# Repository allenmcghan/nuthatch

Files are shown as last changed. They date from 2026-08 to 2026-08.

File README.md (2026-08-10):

# Nuthatch — An Open Single-Seat Ultralight

The Part 103 fleet is mostly 1980s designs. They are cheap, they are buildable in
a garage, and they hurt people in a small number of well-understood ways:

- **Ground loops**, because almost all of them are taildraggers
- **Stall-spin departures**
- **Nothing structural ahead of the pilot's legs**
- **Lap belts instead of harnesses**
- **A 7:1 glide**, so an engine failure leaves you very few fields to choose from

Every one of those is fixable for roughly 100 build hours and $1,900. Nuthatch is
what that looks like.

A single-seat wood-and-steel ultralight derived from the TEAM Sky Pup and Ison
Airbike. Plans, drawings, calculations, build log, and measured flight data all
live here. So do the mistakes.

**Named after the only bird that climbs down a tree headfirst.** Small, plain, and
does it backwards from everything else in the class.

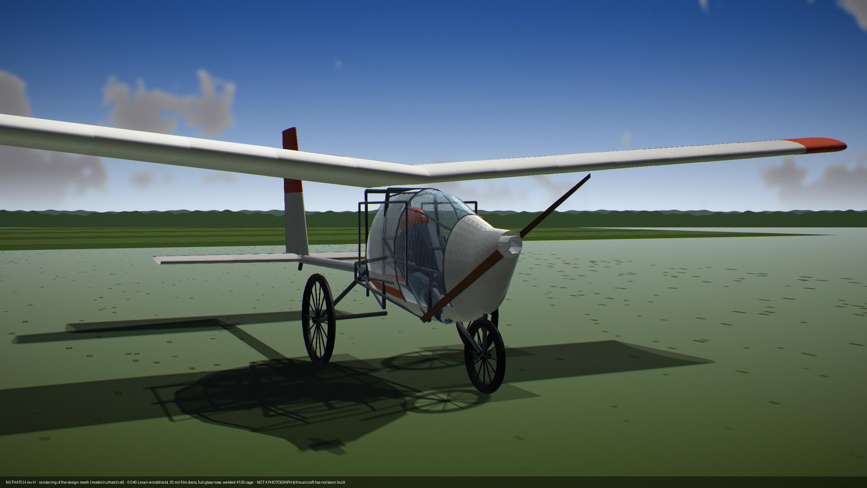
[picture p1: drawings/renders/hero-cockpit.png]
Nuthatch rev H


*A rendering of the design mesh, not a photograph — this aircraft has not been
built. Generated from `model/nuthatch.stl` by `analysis/render-hero.py`.*

**Status: entering final design.** The configuration is settled and reasoned;
the structure is not drawn. There is a 3D model, a drawing set, CAD exports of
the steel frame and a measured visibility analysis — and **no member has been
sized against a load case.** [docs/open-questions.md](docs/open-questions.md)
opens with the four items that gate everything else.

---

## Design targets

| | |
|---|---|
| Cost, materials | under $15,000 |
| Build hours | under 750 |
| Takeoff roll | under 200 ft |
| Fits | a 22 ft garage and a 16 ft flatbed trailer |
| Part 103 | a compliant configuration off the same drawings |

## Current specification

Two configurations, one set of drawings. See [docs/specs.md](docs/specs.md).

| | EAB build | Part 103 build |
|---|---|---|
| Empty weight | 296 lb\* | 250 lb\* |
| Gross | 580 lb | 450 lb |
| Span / area | 31 ft / 130 ft² | same |
| Stall, flaps 40° | 28.4 mph | 22.9 kt |
| Takeoff roll | 140 ft | ~160 ft |
| Climb | 1,010 fpm | ~500 fpm |
| Glide ratio | 12.4† | 12.4† |
| Cruise | 55–60 mph | 55 kt limited |
| Range | ~150 mi | fuel limited |
| Engine | Hirth F-33, 28 hp | direct-drive, ~16 hp |
| Brakes | yes | yes |

\* **Empty weight: two statements, deliberately not reconciled.** The workbook
omits rows (slats — since retired for flaps — and cabane) that the build-log
CSV carries; honest totals are ~308 / ~262 lb. The scrubbed single-build path
reaches 253.2, and the rev G cabane deletion takes the 103 kit to **247.7**.
Reconciliation is parked until the frame is redrawn — see
[docs/specs.md](docs/specs.md).

† **Glide 12.4, not the 10.7 this repo quoted for a long time.** Rev G lowered
the wing onto the cabin roof and deleted the cabane: f 4.84 → 3.68 ft², L/D
10.8 → 12.4. The §22 drag cleanup would take it to 13.6, but that is proposed,
not adopted. Nothing here is measured.

**Powerplant roadmap: gasoline first, hybrid second, electric third.** Electric,
when it comes, is an EAB-only path — a Part 103 all-electric build has 8 lb of
battery budget left after the airframe and drive, which is about four minutes.
Part 103 stays gasoline. Worked in
[docs/trades/pusher-vs-tractor.md](docs/trades/pusher-vs-tractor.md).

## Configuration

- Nose-mounted tractor propeller. Pusher was analysed and rejected for the
  gasoline aircraft: efficiency is a wash, and it does not close on balance
- Welded 4130 cockpit cage + single straight 4130 tail boom, all-wood
  cantilever wing sitting directly on the cabin roof (no cabane), fabric
  over everything
- Reclined pilot; **the entire nose is glazed** — from the cowl joint back to
  the wing leading edge and down to the cage's lower longeron, in thin (0.040)
  Lexan. The engine cowl is the only opaque panel forward of the pilot. The two
  doors are thin clear film; a mounted film cutter is the egress tool
- Ram-air NACA ducts, closable for winter — the cabin deletes ~20 °F of wind
  chill rather than making heat. **Doors both sides are an EAB kit item**;
  the Part 103 aircraft carries the windshield and vents without them
- Constant chord, 3-piece removable wing, two bolts per cap per joint
- Douglas fir truss ribs, plywood D-tube leading edge, Oratex covered
- Aluminum tube spar caps with a wrapped sheet shear web
- Single-lever plain flaps, inboard ~60% span (0/25/40°, one-piece torque
  tube; replaced the fixed slats — [docs/trades/flaps.md](docs/trades/flaps.md))
- Two-axis control: elevator and rudder, roll via spoilerons and dihedral —
  one stick (pitch fore/aft, spoilerons lateral, twist-grip rudder), left-hand
  symmetric spoiler lever for glidepath; no rudder pedals
- Tricycle gear, castoring raked nose leg, trailing-arm mains with MTB
  coil-overs, bicycle hydraulic disc brakes
- Structural nose bow ahead of the pilot's feet, rollover hoop, 5-point
  harness anchored to the cage, mesh sling seat over a crushable
  bottom-out pad (energy-absorbing, without the rebound of a bare sling)
- BRS hard points designed in

## What makes it different

**Glide.** 12.4:1 predicted against roughly 7 or 8 for the aluminum-and-Dacron
aircraft in this class. That is a safety number as much as an efficiency one: engine-out you
reach twice the ground area.

**Crash structure.** Steel tube nose bow forward of the pedals and a rollover
hoop behind your head, so there is a survivable volume rather than fabric.

**Visibility, measured.** 61.3% of the whole sphere gets out, and 42% of the
±30° ahead-and-down sector a pilot lands on — against 40.0% and 4% for the
half-glazed version this replaced. Ray-cast from the pilot's eye against the
same mesh the drawings come from, in
[analysis/visibility.py](analysis/visibility.py). The straight-ahead view is
limited by the **engine**, not the glazing, and that is written down too.

**No ground loop.** Tricycle gear with a steerable nose.

**No aileron spin mode.** Roll comes from spoilerons, which produce proverse yaw
and cannot be cross-controlled into a spin.

**A fail-safe autopilot path.** Spoilerons are single-acting with spring return,
so an autopilot servo has no failure mode that takes roll control away from the
pilot. See [Junco](https://github.com/allenmcghan/junco).

## Repository layout

```
docs/specs.md        the current specification, one page, with sources
docs/design-log.md   every decision and the number behind it
docs/open-questions.md   what blocks drawing, most-blocking first
docs/trades/         21 worked configuration trades — index in its README
analysis/            the models: frame, aero, visibility, weights, CAD export,
                     geometry and renderers. Everything regenerates from here
cad/                 DXF, AutoCAD script, tube schedule — from analysis/frame.py
drawings/sheets/     GA-001, LG-001, CP-001, ST-001 + the collected PDF
drawings/renders/    shaded renderings and the visibility chart
model/               nuthatch.stl (rev H) and the quarter-scale validation plan
build-log/           measured weights against estimates, failures
flight-test/         Phase I plan and logged data
```

Detail drawings (`drawings/wing`, `fuselage`, `tail`, `gear`, `fittings`) are
empty placeholders — that is the work of the final design phase.

## CAD

The steel frame lives in [analysis/frame.py](analysis/frame.py) as a node and
member table — not as drawing geometry. Everything downstream reads it, so
moving a node updates the STL, the drawings, the cut list, the weight and the
visibility numbers together. [cad/](cad/) holds the generated DXF, an AutoCAD
script and the tube schedule; `cad-export.py --from-dxf` reads an edited DXF
back. Recommended CAD and the round trip are in [cad/README.md](cad/README.md).

The first thing that check found: **the frame is currently in six disconnected
pieces** — see [docs/open-questions.md](docs/open-questions.md).

## The two files worth reading first

**[docs/design-log.md](docs/design-log.md)** — every decision and the number
behind it, including the configurations that lost and why. Drawings exist for a
dozen aircraft in this class. Reasoning does not.

**[build-log/measured-weights.csv](build-log/measured-weights.csv)** — estimated
against actual weight, part by part, as parts arrive. Every published weight in
this class is a claim. This one will be a measurement.

## Contributing

Corrections to the analysis are the most valuable contribution, especially on
spar sizing, flap geometry, and load cases. Open an issue with your numbers.

## License

Documentation and drawings: CERN-OHL-S v2 (see [LICENSE](LICENSE)).
Firmware and tooling, where present: MIT.

## Disclaimer

**This is an experimental amateur-built aircraft design published as a work in
progress. It has never been built or flown.**

Nothing here has been reviewed, certified, or validated by any authority. The
structural analysis is preliminary and every weight is an estimate until the
build log says otherwise. Slat geometry, spar sizing, and load cases are
explicitly unresolved.

If you build from this, **you are the manufacturer.** You are responsible for
your own structural analysis, your own airworthiness determination, and your own
decision to fly. No warranty of any kind is offered or implied, expressed or
otherwise, including fitness for any purpose.

Aircraft built to Part 103 require no pilot certificate. That does not make them
safe to fly without training. Get instruction.

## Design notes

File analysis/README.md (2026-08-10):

# analysis

The models. Every number quoted anywhere in this repo comes from one of these,
and every drawing, render and CAD file regenerates from them.

Most take an optional scratch-directory argument (where the intermediate mesh
JSON is written); with no argument they use the current directory.

## The source of truth

| | |
|---|---|
| **`frame.py`** | **the steel frame as a node table, a member table and a stock table.** Not a drawing — a design. Run it directly for the tube schedule, the joint angles and the connectivity check. Everything structural reads it |
| `geometry-mesh.py` | builds the whole aircraft: wing, tail, pod, glazing, cowl, boom, gear, plus the frame from `frame.py`. Writes `model/nuthatch.stl`, the mesh JSON and the general-arrangement sheet |

## Analysis

| | |
|---|---|
| `aero-model.py` | AeroSandbox + NeuralFoil: CLmax, Oswald efficiency, dihedral derivatives |
| `visibility.py` | ray-cast from the pilot's eye — what the pilot can see, and what blocks it |
| `trim-tail.py` | tail sizing, trim, stick force, flare authority, rudder-roll rate |
| `weight-scrub.py` | line-by-line weight scrub against the Part 103 cap |
| `common-airframe.py` | the two-configuration fleet: balance, Vne, ballast |
| `gear-design.py` | stance, stroke, drop loads, nose-over protection |
| `flaps.py` | flap increment, VFE, stall margin |
| `cage-design.py` | all-steel boom trade, wing attach loads, cage station convergence |
| `enclosed-cockpit.py` | recline, CG, wing height, drag, the rev G ledger |
| `glazing-ventilation.py` | glazing weight (measured off the mesh), tautness, ram-air flow, wind chill, egress, the enclosure ledger |
| `twist-grip-rudder.py` | wrist torque, horn balance, gearing |
| `sling-seat.py` | sling tension, crush pad, proof load |
| `borrowed-optimizations.py` | VGs, gap seals, drag cleanup, ground-adjustable prop |
| `fly-by-wire.py` | servo weights, hardover authority, the case against |
| `fuselage-boom.py` | **superseded in part** — boom sizing method stands, its aluminium answer does not |

## Output

| | |
|---|---|
| `cad-export.py` | writes `cad/` — DXF, AutoCAD script, tube schedule. `--from-dxf FILE` reads an edited DXF back |
| `cad-sheets.py` | the dimensioned drawing sheets, GA-001 / LG-001 / CP-001 / ST-001 |
| `render-hero.py` | shaded renderings, including the pilot's-eye view |
| `render-kxnx.py` | the takeoff renderings |

## Regeneration order

`frame.py` → `geometry-mesh.py` → everything else. If you change the frame or
the pod, run it in that order; the mesh JSON is what the CAD sheets, the
renderers and the visibility analysis all read.

```
python3 analysis/frame.py
python3 analysis/geometry-mesh.py
python3 analysis/cad-export.py
python3 analysis/cad-sheets.py
python3 analysis/visibility.py
python3 analysis/render-hero.py
```

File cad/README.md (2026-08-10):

# CAD

The steel frame, exported for a CAD package. **Everything in this folder is
generated** — `analysis/frame.py` is the source of truth, and
`analysis/cad-export.py` writes these files from it.

Units are **inches**. Datum is the aircraft datum used everywhere else in the
repo: **X aft from the propeller plane** (so X is the station number), **Y
right**, **Z up**, **ground at z = 0** with the gear at static. Set your CAD
units to inches and it lands in the right place with no scaling.

| File | What it is |
|---|---|
| `nuthatch-frame-3d.dxf` | 3D wireframe, every tube centreline, on layers by structure group, with node markers, node labels and datum/station reference lines. **This is the one to open and start moving.** |
| `nuthatch-views-2d.dxf` | Side / top / front orthographic projections on one flat sheet, with a station grid and waterlines. For drafting, not for editing. |
| `nuthatch-frame.scr` | An AutoCAD script that draws the same wireframe with `LINE` commands. For when a DXF import argues with you. |
| `tube-schedule.csv` | Cut list: every member, stock, centreline length, weight, and the tightest joint angle at each end. |
| `nodes.csv` | Every node, mirrored, with the members that land on it. |

`model/nuthatch.stl` alongside is the full aircraft as a mesh — good for
visualising and for checking clearances, useless for editing.

## Two things these files are not

**They are not a fabrication drawing.** No member has been sized against a
load case. `docs/open-questions.md` carries *"cage member sizing + a rollover
load basis"* as unresolved and no rollover standard has been chosen. The tube
sizes here carry the right geometry and a plausible weight and nothing more.
**Do not cut steel from them.**

**Lengths are centreline to centreline.** Deduct for the fishmouth at each
end. The `min_joint_angle` columns are there because that is what sets the
notch — anything much under 20° is a bad joint however well you cope it.

## The frame is currently in six disconnected pieces

Run `python3 analysis/frame.py`. Drawn as overlapping cylinders the cage looks
solid; drawn as a graph it is not. Only the 14-node cage box is welded
together. The rear frame, the tail boom and all three gear legs are islands,
and several nodes sit two to three inches away from the member they are
supposed to land on — close enough to read as a joint on a drawing, not close
enough to be one in steel.

That is not a bug in the exporter. It is the actual state of the design, and
it is the first thing worth fixing. See `docs/open-questions.md`.

## Which CAD

**If you want to move geometry and get a cut list back: Onshape, free plan.**
Parametric, runs in a browser, and its **Frames** tool does exactly this job —
sweep tube profiles down a wireframe and it generates a cut list with miter
angles. The free tier requires documents to be public, which for a CERN-OHL-S
project is where the CAD should be anyway. Import `nuthatch-frame-3d.dxf` as a
sketch/curve set, then apply frame profiles to it.

**If you want it offline and open source: FreeCAD.** Matches the licence
posture of the repo. Weaker weldment story than Onshape but it will do it.

**AutoCAD works for what you asked for.** The 3D DXF is native LINE geometry
on sensible layers; move endpoints, add members, delete members. What AutoCAD
will not give you is a cut list or a weight — which is what the round trip
below is for.

**If you have access to SolidWorks, its Weldments module is still the best
tool for this specific job** — structural members along a 3D sketch, automatic
cut list with lengths and end angles. It is the only one of these that was
designed for tube frames from the start.

## Round trip

Edit the wireframe in CAD, save as DXF, then:

```
python3 analysis/cad-export.py --from-dxf path/to/edited.dxf
```

It parses the `LINE` entities, matches each endpoint to the nearest known
node, and reports what moved, what is new and what vanished — then prints a
node table in `frame.py` format to paste back in.

It reads **positions only.** Added members, deleted members and changed tube
sizes have to go into `_M` by hand: a DXF line has no way to tell you which
stock it is meant to be.

Once `frame.py` is updated, re-run and everything downstream follows:

```
python3 analysis/frame.py                    # weight, joints, connectivity
python3 analysis/cad-export.py               # these files
python3 analysis/geometry-mesh.py            # STL + mesh + general arrangement
python3 analysis/cad-sheets.py               # drawing sheets
python3 analysis/visibility.py               # what the pilot can see
python3 analysis/render-hero.py              # renders
```

Keep `frame.py` as the source of truth. If the CAD becomes the master, the
weights, the drawings and the visibility numbers quietly stop matching the
aeroplane.

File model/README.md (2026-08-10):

# model/

`nuthatch.stl` is the **full-size rev H aircraft**, generated by
`analysis/geometry-mesh.py` — cage, glazing, cowl and boom all modelled
explicitly. Good for visualising and checking clearances; not editable. The
editable frame is `analysis/frame.py`, exported to `cad/`.

The rest of this file is the quarter-scale validation aeroplane.

---

# Quarter-Scale Validation Model

Built before the full-size airframe to prove the handling before committing to a
garage build.

## Why quarter scale and not eighth

Reynolds number is the whole issue and scale is the only lever on it. For Froude
similarity, weight goes as scale cubed and speed as the square root:

| Scale | Span | Froude weight | Froude speed | Re |
|---|---|---|---|---|
| 1/8 | 46 in | 0.97 lb | 12 mph | 57,000 |
| 1/4 | 7.75 ft | 7.75 lb | 16.5 mph | 161,000 |
| Full | 31 ft | 496 lb | 33 mph | 1,280,000 |

Quarter scale is three times the Reynolds number and still an ordinary large RC
aircraft at 15 oz/ft². It is also big enough that the wing joint and the spoileron
linkage are real mechanisms rather than miniatures.

**Practical note:** at Re 161,000 the section's CLmax is nearer 1.1 than 1.4, so
the model will not fly at exact Froude weight. Build to 5 to 6 lb and fly at 18 to
22 mph. Dynamic frequencies come out slightly faster than scale, so it will feel
twitchier than the full-size. That is the conservative direction.

## What this model can validate

- Pitch stability and usable CG range
- Spiral and dutch roll tendency
- **Roll authority from dihedral plus spoilerons**, which is the single biggest
  open handling question on a two-axis aircraft
- Spoileron versus rudder control power balance
- Trim
- Wing joint concept, assembly, and fit

## What it cannot validate

- CLmax and stall speed
- **Slat effectiveness or geometry.** A slat re-energizes a turbulent boundary
  layer, and at Re 161,000 the boundary layer is largely laminar. Slat dimensions
  that work at 1.28 million read as pure drag on the model.
- L/D and drag numbers
- Stall behavior, which can reverse from root-first to tip-first at low Re
- Structural loads, since Froude scaling makes model loads nothing like full size

**Do not let the model talk you out of the slats, and do not let it size them.**

## Construction

Foamboard fuselage and tail. **Hot-wired XPS wing cores**, not foamboard, because
foamboard bends into a rough approximation of an airfoil and the point is to learn
how this specific section behaves.

## Power and cost

At 5.5 lb and 70 W/lb, level flight needs about 70W; a 400W system gives climb and
wind margin with 15 to 20 minutes per pack.

| | |
|---|---|
| XPS cores, foamboard, carbon tube spars | $140 |
| Balsa and ply for ribs, formers, hardpoints | $50 |
| Adhesives | $40 |
| 400-500W outrunner, 40-60A ESC, two 4S 4000mAh, props | $170 |
| Five servos and receiver | $80 |
| Gear, wheels, linkage, horns, hinges | $60 |
| Tape, paint, hardware | $70 |
| **Total** | **~$610** |

Add a transmitter and charger if not already owned.

## Instrumentation

Runs Junco: ESP32 with an IMU, pitot, and SD logging. That converts "the roll felt
sluggish from 200 ft away" into logged roll rate against stick position.

The model doubles as the Junco development airframe, where a crash costs $600.

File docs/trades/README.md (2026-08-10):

# Trades

Twenty-one worked configuration trades. Each one closes with a *"what this does
not settle"* section, and the ones that lost are written up as carefully as the
ones that won — drawings exist for a dozen aircraft in this class, reasoning
does not.

The narrative order and the decisions live in
[../design-log.md](../design-log.md). This is the index.

## Configuration

| Trade | Outcome |
|---|---|
| [pusher-vs-tractor](pusher-vs-tractor.md) | **Tractor.** Efficiency is a wash; balance diverges and the unblown tail loses authority at rotation. A pusher, if ever, arrives with an electric conversion |
| [propeller-blade-count](propeller-blade-count.md) | **Two blades**, comfortable to ~1750 rpm — 3–4 dB free. Don't shrink the 60 in disc |
| [winglets](winglets.md) | **No winglets.** Span isn't constrained, and the Oswald uncertainty is wider than the benefit |
| [wingtip-caps](wingtip-caps.md) | **Moulded carbon tip caps** instead — weight-neutral, and a shape fabric cannot hold |
| [v-tail](v-tail.md) | **Rejected.** Same area for no weight saved, plus a mixer, routine saturation in the flare, and adverse roll fighting the steering |
| [amphibious](amphibious.md) | **Rejected.** Properly sized floats put their bows forward of the prop disc |
| [fly-by-wire](fly-by-wire.md) | **Rejected**, except the spoileron servo — the only surface whose fail-safe already covers one |

## Structure

| Trade | Outcome |
|---|---|
| [fuselage-architecture](fuselage-architecture.md) | **Pod and boom**, not a full-length truss — ~80 fishmouth joints and the aft jig deleted. *(Its aluminium boom was reversed — see below)* |
| [cockpit-cage](cockpit-cage.md) | **All-steel.** CG, front spar and rollover hoop converge within 2.5 in, so **one frame at sta 61.5 does three jobs**. A thin-wall boom is buckling-limited, so steel wins it back |
| [enclosed-cockpit](enclosed-cockpit.md) | **Reclined pilot, wing onto the cabin roof, cabane deleted.** L/D 10.8 → 12.4, and −5.5 lb that paid for the steel boom |
| [seat](seat.md) | **Mesh sling over a crushable pad** — ~1.8 lb, and the energy absorption survives. Proof test to 1,920 lb |
| [landing-gear](landing-gear.md) | **Trailing arms on MTB coil-overs, bicycle wheels, raked nose leg.** Nose-over protection 17.9° → 35.5° |

## Aerodynamics and loads

| Trade | Outcome |
|---|---|
| [design-audit](design-audit.md) | The end-to-end audit that **broke the load basis** — slats broke the stall-limit argument, no negative-g case existed, and level flight exceeded Vne |
| [flaps](flaps.md) | **Single-lever plain flaps replace the fixed slats.** Escape clause: a wing drop on the quarter-scale demo reverts it |
| [trim-tail](trim-tail.md) | **Tail confirmed as drawn.** The elevator commands stall at every speed and CG; the flare passes at forward CG in ground effect |
| [borrowed-optimizations](borrowed-optimizations.md) | What the rest of the ultralight world has that this design should take — VGs, gap seals, drag cleanup, a ground-adjustable **wood** prop |

## Fleet, weight and process

| Trade | Outcome |
|---|---|
| [common-airframe](common-airframe.md) | **One airframe, two kits.** Vne 62 mph fleet-wide makes the spar stall-protected at every gross for free |
| [weight-scrub-103](weight-scrub-103.md) | The two weight statements disagree; line-by-line scrub finds −41 lb. **Reconciliation is currently parked** — see [../specs.md](../specs.md) |
| [digital-fabrication](digital-fabrication.md) | **Tooling, not flight parts.** No laser holes at final size, no laser-cut structural ply |
| [second-build](second-build.md) | 370–460 hours with tooling in hand. **Aircraft #2 deferred until #1 proves out** |

## Superseded, and marked as such

- **[fuselage-architecture](fuselage-architecture.md)** chose a **6061-T6
  aluminium boom**. Rev F reversed it to 4130 steel — the architecture stands,
  the material does not. The banner is at the top of the file, and
  `analysis/fuselage-boom.py` carries the same warning.
- The **fixed slats** in the early sections of the design log were replaced by
  flaps. The **cabane** was deleted by rev G. Both survive in the log because
  the reasoning that retired them is the useful part.

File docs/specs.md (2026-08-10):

# Specification

**Rev H, entering final design.** One page, current numbers, with the source of
each. Where the repo carries two numbers for the same thing, both are here and
so is the reason.

Nothing has been built or flown. Every performance figure is a prediction and
every weight is an estimate.

---

## Geometry

Datum: **X aft from the propeller plane** (so X is the station number, inches),
**Y right**, **Z up**, **ground at z = 0** with the gear at static. Every
drawing, script and CAD file in the repo uses it.

| | | Source |
|---|---|---|
| Span | 31 ft | |
| Wing area | 130 ft² | |
| Chord | 50 in, constant | |
| Aspect ratio | 7.39 | |
| Section | NACA 4412 | [design-audit](trades/design-audit.md) addendum |
| Dihedral | 5° per side | `aero-model.py` |
| Washout | 2.5° | |
| Wing LE | sta 48; chord line z 58, underside z 55 | design-log §25 |
| Wing | 3-piece removable, two bolts per cap per joint | |
| Cage | sta 30 – 96, welded 4130 | [cockpit-cage](trades/cockpit-cage.md) |
| Main hoop | **sta 61.5** — front spar + rollover + CG on one frame | design-log §24 |
| Rear frame | sta 80.5 — rear spar, seat back, harness anchor | |
| Tail boom | sta 96 – 184, **3.50 × .049 4130, constant section** | design-log §24 |
| Tail | 30 ft² horizontal + 15 ft² vertical, elevator 45% chord ±25° | [trim-tail](trades/trim-tail.md) |
| Thrustline | z 40 | [landing-gear](trades/landing-gear.md) |
| Propeller | 60 in disc, two blades, wood | [propeller-blade-count](trades/propeller-blade-count.md) |
| Mains | sta 70.5, track 56 in | |
| Belly | 16 in AGL, seat 20 in | |

Full node and member table: [`analysis/frame.py`](../analysis/frame.py).
CAD exports: [`cad/`](../cad/).

## Limits

| | | Source |
|---|---|---|
| **Vne** | **62 mph, fleet-wide** | [common-airframe](trades/common-airframe.md) |
| VFE | 55 mph | [flaps](trades/flaps.md) |
| Gross, EAB | 580 lb | |
| Gross, Part 103 | 450 lb (stall gate caps it at 456) | [weight-scrub-103](trades/weight-scrub-103.md) |
| Structural pilot cap | 200 lb | |
| Ballast placard | 8 lb nose below a 135 lb pilot | |

Vne 62 is not a performance limit — it is the **load basis**. At 62 mph the
wing stalls before it can be overstressed, at every gross, with zero added
weight. Every load case in the repo depends on it.

## Performance, predicted

| | EAB | Part 103 | Source |
|---|---|---|---|
| Stall, flaps 40° | 28.4 mph | 22.9 kt | [flaps](trades/flaps.md) |
| Takeoff roll | ~140 ft | ~160 ft | |
| Climb | ~1,010 fpm | ~500 fpm | |
| **Glide ratio** | **12.4** | 12.4 | design-log §25 |
| Cruise | 55–60 mph | 55 kt limited | |
| Range | ~150 mi | fuel limited (5 gal) | |
| Engine | Hirth F-33, 28 hp | direct-drive ~16 hp, Thor-DS class | [weight-scrub-103](trades/weight-scrub-103.md) |

**On the glide number.** The repo quoted **10.7** for a long time. Rev G lowered
the wing onto the cabin roof and deleted the cabane, which took f from 4.84 to
3.68 ft² and L/D from 10.8 to **12.4**. If the §22 drag cleanup is adopted —
wheel pants on the mains, streamlined tube, footwell closeout — it goes to
**13.6**, but those are *proposed, not adopted*. **12.4 is the number of
record.** None of it is measured.

## Weight — two statements, deliberately not reconciled

| | EAB | Part 103 | Source |
|---|---|---|---|
| Workbook | 296 lb | 250 lb | `weight-cost-hours.xlsx` |
| Build-log CSV, honest | ~308 lb | ~262 lb | `measured-weights.csv` |
| Scrubbed single-build path | — | 253.2 lb → **247.7 lb** after the cabane deletion | design-log §25 |
| Part 103 limit | — | 254 lb | §103.1(e)(1) |

The workbook omits rows the CSV carries. **This is parked by owner decision**,
not resolved: the frame is being redrawn by hand, and reconciling a workbook
against superseded geometry buys nothing until that lands. Quote the source,
not a consensus.

Two things that *are* measured off the current geometry:

- **Steel frame, tube only: 48.4 lb** — 27.5 cage, 13.2 boom, 7.7 gear. No
  gussets, no fittings, no weld metal. [`cad/tube-schedule.csv`](../cad/tube-schedule.csv)
- **Enclosure kit: 14.4 lb gross** — glazing, frames, bead track, cutters,
  ducts, closeout. `analysis/glazing-ventilation.py`

## Configuration

- **Nose-mounted tractor.** Pusher analysed and rejected for the gasoline
  aircraft — [pusher-vs-tractor](trades/pusher-vs-tractor.md)
- **All-steel airframe**: welded 4130 cage + single straight 4130 boom, all-wood
  cantilever wing sitting directly on the cabin roof, no cabane, fabric over
  everything
- **The entire nose is glazed** — cowl joint at sta 22 back to the wing leading
  edge, down to the cage's lower longeron. **0.040 Lexan**; the engine cowl is
  the only opaque panel forward of the pilot. Two doors in 20 mil clear film
- **Ram-air NACA ducts**, closable for winter. Doors both sides are an **EAB kit
  item**; the 103 carries windshield and vents without them
- **Two-axis control**: elevator and rudder, roll via spoilerons and dihedral.
  One stick — pitch fore/aft, spoilerons lateral, **twist-grip rudder** — plus a
  left-hand symmetric spoiler lever. **No rudder pedals**
- **Single-lever plain flaps**, inboard ~60% span, 0/25/40°, one-piece torque
  tube (replaced the fixed slats)
- **Tricycle gear**: castoring raked nose leg with the wheel just aft of the
  prop disc, trailing-arm mains on MTB coil-overs, bicycle hydraulic discs
- **Crash structure**: nose bow ahead of the feet, rollover hoop, 5-point
  harness to the cage, mesh sling seat over a crushable bottom-out pad
- **BRS hard points** designed in
- Douglas fir truss ribs, plywood D-tube leading edge, **Oratex** covering,
  aluminium tube spar caps with a wrapped sheet shear web

## Visibility, measured

Ray-cast from the pilot's eye against the mesh — [`analysis/visibility.py`](../analysis/visibility.py).

| Sector | rev G | **rev H** |
|---|---|---|
| whole sphere | 40.0% | **61.3%** |
| forward hemisphere | 45.3% | 67.9% |
| the approach window | 48.9% | 74.7% |
| ahead and down, ±30° | 4.2% | **41.9%** |

Straight ahead is limited by the **engine**, not the glazing: the cowl crown
sits 1.8 in above the eye, so there is no over-the-nose depression angle at all.
See design-log §26 and the cowl-height item in
[open-questions](open-questions.md).

## Fleet rule

**One airframe, two bolt-on kits**, both balancing on the same wing position.
Aircraft #1 registers EAB by choice; aircraft #2 stays a pure Part 103 for a
105 lb pilot, and is **deferred until #1 proves out**. Glazing is a kit item
either way — the EAB takes the Lexan nose, the 103 takes film in the same frame
and the same bead track, because at rev H the 103 cannot afford the Lexan.

## What this page is not

It is not a build standard. **No structural member has been sized against a
load case**, no rollover load basis has been chosen, and the frame is currently
in six disconnected pieces. See [open-questions.md](open-questions.md) — the
four items at the top of it gate everything here.

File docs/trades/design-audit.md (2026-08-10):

# End-to-End Design Audit

A full simulation pass over the aircraft as documented: every published
performance number re-derived from the workbook's own model, then the design
log's load, stability, and mission claims stressed against it.

**Headline: the performance numbers all reproduce. The load basis does not.**
Four real findings, one of them structural, plus one genuinely cheap improvement.

| # | Finding | Severity |
|---|---|---|
| 1 | §12's stall-limit argument fails with fixed slats — the wing **can** be aerodynamically overstressed | **structural** |
| 2 | No negative-g load case exists; gusts reach −1.9 at Vc | structural |
| 3 | Full-throttle level flight (~80 mph) exceeds Vne (69) | operational |
| 4 | The Part 103 takeoff claim doesn't survive the deleted redrive | performance |
| 5 | Landing over the mission's own trees is the binding field constraint — a symmetric-spoiler mode fixes it | improvement |

Status: analysis. Nothing changed except a correction note in design-log §12.

---

## A. What reproduces (all PASS)

Re-derived independently from the Performance-sheet model (f = 0.45/0.519 m²,
e = 0.85, ηp 0.75/0.72):

| Claim | Published | Audit | |
|---|---|---|---|
| Stall clean, 496 lb | 32.7 mph | 32.7 | PASS |
| Stall slats, 496 lb | 28.8 mph | 28.8 | PASS |
| 103 stall slats, 450 lb | 23.8 kt | 23.8 | PASS |
| EAB takeoff roll | 140 ft | 140 | PASS |
| EAB climb | 1,010 fpm | ~1,050 | PASS |
| Glide ratio | 10.7 | 10.7 | PASS |
| Range | ~150 mi | ~150 | PASS |
| Tail volumes | — | Vh 0.56, Vv 0.038 | in band, correctly rudder-heavy |
| Loaded CG | 28–31% MAC | 28.3–30.8% | PASS |

The arithmetic and the model are internally consistent. The problems are in what
was never modelled.

## B. Finding 1 — the stall-limit argument is broken by the slats (structural)

§12: *"The most g a wing can generate is (V/Vs)². At Vne 69 and a 32.7 mph
stall, that is 4.65. … The aircraft cannot be aerodynamically overstressed."*

Two problems, one small and one not.

**Small:** (69/32.7)² = **4.45**, not 4.65. The conclusion survived; the
arithmetic didn't.

**Not small:** §10 makes the slats **fixed, full-span**. CLmax 1.8 is therefore
always available — the 32.7 mph clean stall used in §12 never exists in flight.
Recomputed at the slatted CLmax:

| Condition | Vs, slats | n available at Vne | vs 4.7 limit |
|---|---|---|---|
| EAB max gross, 580 lb | 31.1 mph | 4.91 g | exceeds |
| Design point, 496 lb | 28.8 mph | **5.74 g** | **exceeds** |
| 103 gross, 450 lb | 27.4 mph | 6.33 g | exceeds |
| 130 lb pilot, no fuel, 426 lb | 26.7 mph | 6.69 g | exceeds |

In absolute terms: at Vne the wing can generate q·S·CLmax = **2,848 lb** of lift
regardless of weight. Ultimate as sized is 7.0 × 496 = 3,472 lb; pulling to CLmax
at Vne needs 2,848 × 1.5 = **4,272 lb — a 23% shortfall.**

A full-aft-stick pull at Vne — precisely the manoeuvre §12 says is safe — can
exceed limit load at every flight weight, and ultimate is not covered.

**Three fixes, cheapest first:**

1. **Lower Vne to Vs_slats·√4.7 ≈ 62 mph.** Costs nothing structurally; cruise
   is 55–60, so it thins the cruise-to-Vne margin to almost nil. Probably too
   tight to live with alone.
2. **Raise limit load to 5.74 g (ultimate 8.6).** By §12's own pricing of ~4 lb
   per 0.7 g, roughly **+6–10 lb of cap**. This restores the "cannot be
   overstressed" property *honestly* — with the slatted stall speed in the
   formula, which is the aircraft that is actually being built.
3. **Show the elevator cannot command CLmax at high speed.** Possibly true —
   slats push the stall to very high alpha, and the tail may run out of authority
   first — but it converts a structural guarantee into a tail-analysis result
   that doesn't exist yet, on an aircraft whose tail is also the roll control.

Option 2 is the recommendation. The whole point of §12 was that the envelope
protects the structure; 6–10 lb buys that property back for the aircraft as
actually configured.

**Update — option 3 is closed.** The gate-3 trim analysis
([trim-tail.md](trim-tail.md)) shows full-up elevator commands 1.6–2.2× the
slatted CLmax at every CG: the wing stalls before the elevator runs out, at any
speed in the envelope. There is no tail-authority protection, and cutting the
throw to create one (~−11°) cannot flare the airplane (needs −19.3°). The
choice is now option 2 (+6–10 lb of cap, recommended) or option 1 (Vne ≈ 62).

**Corollary for fittings:** the g available rises as weight falls (6.7 g at
426 lb). Fixed-mass items — engine mount, seat, harness anchors, BRS hard
points — see n × (their own fixed mass), so they should be sized at the
**light-weight** load factor, not the gross-weight one. §12 already says to
spend margin on fittings; this says how much.

## C. Finding 2 — there is no negative-g case anywhere

§12 sets +4.7/+7.0 and stops. FAR 23.341-form gust analysis at the project's own
numbers (a = 4.42/rad, μ from 3.8 psf wing loading):

| Condition | Gust | n |
|---|---|---|
| Vc 60 mph, design weight | ±50 fps | **+3.69 / −1.69** |
| Vc 60 mph, light | ±50 fps | +3.90 / **−1.90** |
| Vne 69 mph | ±25 fps | +2.55 / −0.55 |

Positive gusts stay inside +4.7 — the manoeuvre case governs, good. But
**−1.9 g at Vc is a real load with no corresponding structural case.** A
conventional pairing would be −1.9 limit / −2.85 ultimate.

This matters more than usually because the spar is **asymmetric**: §7's web is
wrapped from one face down and under, riveted at the top, and the cap-to-web
riveting pattern differs top versus bottom. Reversed bending loads the web wrap
and rivet line in the direction it was not shaped for. The V-n diagram already
in open questions should carry the negative branch explicitly, and the spar
detail should be checked in reversed bending before drawings freeze.

## D. Finding 3 — the aircraft out-runs its own Vne

Solving power available = power required at full throttle, slats installed:
**Vmax level ≈ 80 mph, against Vne 69.** The margin is not small — 21 available
hp against 27.7 required at 80.

An aircraft that can exceed Vne in *level* flight at full throttle — never mind
a shallow descent — puts redline discipline entirely on the pilot. Combined with
Finding 1 (a pull at Vne already over-stresses), this is the worst corner of the
envelope: fast, full power, and a gust or a pull.

Mitigations, combinable: pitch the cruise prop so the engine runs out of rpm
near Vne (fixed-pitch props do this naturally — choose the pitch with this in
mind, not just cruise economy); placard and trim accordingly; and if Finding 1
is fixed by raising the load basis (option 2), some of this concern retires with
it because Vne itself can then be reviewed honestly.

## E. Finding 4 — the Part 103 takeoff number doesn't survive the deleted redrive

The 103 strip column deletes the belt redrive (10 lb → 0) and assumes a
direct-drive ~16 hp engine. A direct-drive two-stroke turns 5,000–6,000 rpm, and
tip speed caps the prop:

| Direct drive | Max prop (0.8 M tip) | Static thrust | Ground roll @ 424 lb |
|---|---|---|---|
| 5,800 rpm | ~35 in | ~96 lb | **~340 ft** |
| 5,000 rpm | ~42 in | ~114 lb | **~240 ft** |

The README claims ~160 ft, and the design target is under 200. **A direct-drive
prop cannot deliver either number.** The deleted 10 lb redrive — which lets the
same engine swing the 60 in disc at ~230 lb static — is worth roughly **140 ft
of runway**, on the configuration that flies from a 1,000 ft field.

Either the 103 keeps a (lightened) redrive and finds the ~8 lb somewhere else in
the strip, or the README's 103 takeoff and climb figures need rewriting around a
small direct-drive prop. The open-questions item about "the 103 engine's actual
power rating" is the wrong question — **the prop diameter the drive can turn is
what decides the field performance.**

## F. Finding 5 — the mission's binding constraint is landing over its own trees

The field: 300 × 1,000 ft with trees at one end (§0). Takeoff toward 50 ft trees
is comfortable — 140 ft roll plus ~140 ft climbing at gradient 0.36 clears them
in under 300 ft.

**Landing back over those trees is not comfortable.** At L/D 10.7 power-off with
no glidepath control: 536 ft of air from tree-crossing, plus flare, plus the
84 ft roll — **~720 of the 1,000 ft, before any error.** And a two-axis aircraft
cannot slip: spoilerons are the roll control and there is no cross-control to
slip with. Throttle is the only glidepath tool, and engine-out there is none.

The high glide ratio that is the aircraft's safety headline is, on final over an
obstacle, a liability.

**The fix is already on the aircraft.** The spoilerons exist; they are
single-acting, tension-only, spring-return (§9). Add a **symmetric deployment
mode** — both spoilers up together, on a separate lever or an over-centre detent
past full stick travel. At an effective L/D of ~6 the same landing takes
**~484 ft**, and every failure mode still resolves to spoilers-closed by the
same spring-return architecture that §9 already requires. Gliders have operated
exactly this system for ninety years.

This is the single cheapest meaningful improvement the audit found: no new
surfaces, no new structure, one cable path and one lever, and it converts the
mission's worst case from marginal to routine. It also partially retires
Finding 3 — deployed spoilers are speed brakes in a descent.

## G. Smaller observations

- **Empty-weight sums check out**: EAB 296 lb, 103 strip 250 lb against the
  254 cap. The 4 lb of 103 margin is thin but real.
- **Fuel CG shift is benign**: 29.2% → 30.8% MAC full-to-empty.
- **Spar root web shear is easy** (~7 ksi at ultimate through the double 0.020
  web); buckling and stiffener spacing remain the open item, as already listed.
- **§13's joint bearing arithmetic verifies** (0.105 in² per bolt pair, two
  bolts per cap → ~108% margin as claimed).
- **Vh 0.56 / Vv 0.038** — horizontal mid-band, vertical at the top of the band,
  which is the right place for an aircraft that rolls with its rudder.

## H. What this audit could not check

- Anything aeroelastic — flutter remains unanalysed, as open-questions now says.
- Dihedral/spoileron roll authority and dutch roll: needs the model (or the
  original Sky Pup values). The audit only confirms the tail volumes are sane.
- Slat CLmax = 1.8 is still an assumption; every stall and field number above
  inherits it, and the 103 stall margin is 0.8 kt.
- The elevator-authority question raised in Finding 1(c) — a real tail analysis
  would either retire Finding 1 cheaply or confirm the +6–10 lb.

---

## Addendum: first computational model (aero-model.py)

The repo now carries a parametric model — `analysis/aero-model.py` (AeroSandbox
VLM + component buildup, NeuralFoil section polars) and `analysis/geometry-mesh.py`
(mesh → `model/nuthatch.stl`, `drawings/general-arrangement.png`). Interactive
viewer with results published as an artifact. New results on top of the audit:

**The CLmax 1.4 assumption is sound.** NACA 4412 makes 1.61 in 2-D at the stall
Reynolds number (1.12 M); a finite wing delivers ≈0.9× section, ≈1.45. Candidates:
4412 CLmax 1.61 / cd 0.0059 at cruise CL; 6409 1.67/0.0069; 4415 1.60/0.0069;
2412 1.51/0.0063 — **4412 is the working recommendation** (best cruise drag, 12%
thick for spar depth, buildable bottom). 2412 misses the assumption; avoid. At the
RC model's Re 161 k the same section drops to 1.42 2-D — confirming model/README's
warning that the model must not size the slats.

**Oswald e is probably 0.72–0.80, not 0.85.** Component buildup with fuselage and
trim gives 0.72. Induced power ~10–18% above what the workbook carries; re-run the
103 climb margin at e = 0.75. Phase I item 7 measures the truth.

**The smooth airframe is only f = 0.084 m² against the 0.45 carried.** So ~80% of
the drag budget is cockpit, pilot, gear, rigging, and cooling — the back-solved
0.45 is not optimistic, and the cleanup upside is in housekeeping, not the wing.

**Static margin 24–40% MAC at 30% CG with the placeholder tail** (VLM low end,
buildup high end). Stable to the point of raising the audit's Finding 1(c) as a
real possibility: the elevator may not command slatted CLmax — but that must be a
designed property, verified by a trim analysis across the CG range, not an
accident of a placeholder tail. It also means big elevator throws to flare.

**Dihedral 5° placeholder survives**: Clβ −0.082 /rad against Cnβ +0.107 /rad is a
healthy rudder-roll ratio with strong weathercock. The dynamic modes (dutch roll,
spiral) remain the quarter-scale model's job.

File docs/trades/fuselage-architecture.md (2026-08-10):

# Fuselage Architecture: Steel Cockpit Cage + One Straight Boom

> **Superseded in part, and worth reading anyway.** This trade selected a
> **6061-T6 aluminium** boom. **Rev F reversed that** — the boom is 4130 steel,
> 3.50 × .049 ([cockpit-cage.md](cockpit-cage.md), design-log §24). A thin-wall
> boom turns out to be buckling-limited rather than strength-limited, so steel's
> stiffness nearly cancels its density, and the aluminium-to-steel transition
> joint disappears with the choice.
>
> **The architecture stands. The material does not.** Everything below about
> pod-and-boom versus a full-length welded truss — ~80 fishmouth joints deleted,
> 35–45 build hours, an aft fuselage that cannot be built out of square — is
> still the design of record.

**The question:** can the fuselage be designed to actually be easy to
construct — a single straight boom to the tail and a simple, aerodynamic
cockpit — instead of what the drawings have been showing?
Script: `analysis/fuselage-boom.py`.

**Short answer: yes, and this is adopted as the architecture (rev E).** The
drawings were wrong, not the idea. What the record actually called for
(design-log §5) was a welded 4130 tube fuselage — but the digital-fabrication
plan silently assumed that truss ran the *full ~190 in* to the tail post, and
the 3D mesh drew a fat continuous body over it. Neither was ever a decided
requirement. The architecture that matches both the mission and the
easy-to-build goal is the one Kolb has used on Part 103-class aircraft for
forty years: a **welded 4130 cockpit cage** carrying everything that needs
steel, and a **single straight aluminum tube boom** carrying the tail.

## 1. What went wrong with the drawings

The mesh lofted one continuous fuselage from the nose to sta 184 with a
cockpit-depth cross-section fading out gradually — it read as a big
slab-sided monocoque. That was a rendering choice, not a structural one; no
trade ever chose that shape. The structure behind it (per
[digital-fabrication](digital-fabrication.md)) would have been a 190-in
welded truss: 130 build hours, a full-length eggcrate jig, and the
out-of-square risk that comes from ~160 hand-coped fishmouth joints. This
trade replaces the aft half of that plan and the drawings both.

## 2. The two architectures

| | Full welded truss (old assumption) | Cage + boom (rev E) |
|---|---|---|
| Aft structure | 4 longerons + ~40 diagonals, sta 96–182 | one 6061-T6 drawn tube |
| Aft weight | ~14 lb + fabric stringers | ~10.5 lb incl. fittings |
| Weld joints aft of cockpit | ~80 fishmouthed ends | zero |
| Aft jig | eggcrate stations, ~90 in of it | none — a drawn tube is straight by manufacture |
| Torsion (rudder loads) | truss must be diagonally braced in all four planes | closed round tube: best torsion section there is; shear works out at 2.7 ksi, trivial |
| Precedent | Airbike, Legal Eagle | **Kolb Firefly (a Part 103 aircraft), Firestar, and the whole Kolb line** |

## 3. Boom sizing

Load basis is the fleet's Vne 62 mph, boom root at the aft cage bulkhead
(sta 96), tail post at 182 — an 86 in arm:

- H-tail max load 295 lb limit → **38,000 in-lb ultimate** bending (matches
  the 37,800 figure the losers table has carried since the inflatable-wing
  trade — good sign the numbers agree with themselves).
- V-tail 147 lb limit → 19,000 in-lb lateral + 6,600 in-lb torsion.

**Selected: 6061-T6, 5.00 in OD × 0.065 wall.** Allowable set by thin-wall
local buckling with a conservative 0.25 knockdown, not by material strength:
47,900 in-lb ultimate → **+26% margin**. The 0.058 wall technically closes at
+1% but that is no margin at all for a tube that will get hangar rash; the
extra 1 lb buys the margin. Tip deflection at limit load is 2.0 in and the
first bending mode is ~8 Hz — both recorded as inputs to the flutter item,
which remains open. Control cables and wiring run *inside* the boom, Kolb
style, which also tidies the aerodynamics for free.

## 4. What stays steel, and why

Design-log §5's argument for steel was never about the aft fuselage — it was
about the concentrated-load hardware: **nose bow, rollover hoop, harness
anchors, gear mounts, engine mount cluster**. All of that lives forward of
sta 96, in the cockpit cage. The cage keeps every crash-structure property
already committed (rev D crush bay, 15 in ahead of the pilot's feet,
included). The cage-to-boom joint is a machined/bolted sleeve collar at the
aft bulkhead; per the project's copy-a-known-installation rule, the boom root
and tail-post fittings get **copied dimension-for-dimension from a Kolb
installation**, not derived.

## 5. The cockpit pod: simple *because* it is not structure

With the cage doing all the work, the pod is pure fairing — windshield line,
a teardrop in plan, closing at the boom junction: four to six wood or
aluminum stringers off the cage, fabric over them, done. No compound-curve
fiberglass unless it is wanted for looks. Shape is free to be aerodynamic
because nothing structural constrains it, and it can change after first
flight without touching a load path.

## 6. Ledger

- **Weight:** boom + fittings ~10.5 lb vs ~14 lb of aft truss and stringers —
  about even to −4 lb. The 55 lb fuselage-structure line in the
  [common-airframe](common-airframe.md) ledger is unchanged; any saving is
  margin, not banked.
- **Hours:** the 130-hour weld-jig-and-fuselage line loses its aft half:
  ~80 fishmouths and the aft jig are deleted. Estimate **35–45 hours saved**,
  and — worth more than the hours — the aft fuselage can no longer be built
  out of square, because it is one bought tube.
- **Airframe invariant:** unaffected. The cage + boom is the same on the 103
  and EAB aircraft; nothing about the kits changes.

## 7. Verdict and gates

**Adopted: welded 4130 cockpit cage (nose to sta 96) + 6061-T6 5.00 × .065
straight boom (sta 96–182), rev E of the geometry.** Gates before drawings
freeze:

1. Copy the Kolb boom-root and tail-post fitting dimensions from a real
   installation (photos and measurements, not the general idea).
2. The flutter item inherits the boom stiffness numbers above (2.0 in tip
   deflection at limit, ~8 Hz first mode) as inputs.
3. Verify 5.00 × .065 6061-T6 drawn tube is actually purchasable in an 88 in
   length (it is a stock Wicks/Aircraft Spruce size class; confirm before
   the structure is drawn around it).

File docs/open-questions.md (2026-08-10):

# Open Questions

These are the items that block drawing, in the order they need resolving.

**Entering final design, four things block geometry and everything else waits
on them:**

| # | What | Why it blocks | Where |
|---|---|---|---|
| 1 | **The frame is in six disconnected pieces** | you cannot draw a structure whose members do not meet | [below](#the-frame-is-in-six-disconnected-pieces), design-log §27 |
| 2 | **Cage member sizing + a rollover load basis** | no member has been sized against a load case, and no rollover standard has been chosen | [below](#verify-before-committing) |
| 3 | **Cowl height** | sets the over-the-nose view, and needs an engine on a bench with a tape on it | [below](#cowl-height-which-sets-the-forward-view), design-log §26 |
| 4 | **Airfoil section and its real CLmax** | stall speed, flap geometry, spar depth and rib templates all hang off it | [below](#blocking-everything) |

Everything else on this page is real but downstream of those four.

## Blocking everything

### The frame is in six disconnected pieces

`analysis/frame.py` turned the cage from thirty hard-coded `strut()` calls into
a node/member graph, and the graph answers a question the tube mesh could not:
**do these tubes actually meet?** Overlapping cylinders look welded. They are
not. `python3 analysis/frame.py` prints the list; this is what it finds.

Only the **14-node cage box** — nose bow, longerons, main hoop, diagonals, aft
frame — is one connected structure. Everything else floats:

| Island | What it is | What it needs |
|---|---|---|
| `RF_L RF_R RP_L RP_R` | the **rear frame**: rear spar carry-through, seat back, harness anchor | `RF` sits **2.70 in** off the lower longeron. Either drop `RF` onto the longeron line, or add a member from `RF` to it. **A harness anchor that is not welded to the cage is not a harness anchor.** |
| `BM_C TP_C` | the **tail boom** | `BM_C` floats **3.00 in** between the two aft-frame crosses. The boom picks up on the aft frame through a fitting that is not modelled. Either model the fitting or move the crosses to meet the tube. |
| `NGU_C NGF_C NAX_C` | the **nose leg** | `NGU_C` is meant to land on the nose bow, but the nose bow is a **U, not a hoop** — there is a crown at `NT_L`–`NT_R` and no lower cross member. Nothing exists at `(30, 0, 17)` to weld to. And `NGF_C` still floats at station 14 (below). |
| `MGF_R MAX_R MGS_R` ×2 | the **main gear** | the trailing-arm pivot `MGF` is 2.4 in outboard and 3.5 in below the lower longeron at that station. Same question: fitting, or move it onto the tube. |

Two more near misses inside the cage box itself, which are the serious ones:

- **The main hoop feet do not land on the longerons.** `MH` is **3.44 in** from
  the lower longeron at 47% along it. That frame carries **88% of wing lift —
  1,519 lb per side fitting** — and is the rollover structure. Its feet have to
  tie into the longerons or into a fitting that does.
- **`NGF_C` attaches to nothing.** Station 14, sixteen inches forward of where
  the cage starts. It came in with the rev D raked nose leg as *"closes the
  crush-bay triangle"* and was never tied to a node. Either it lands on the
  nose bow, or it lands on the engine mount, or the member goes away.

**Nothing has been moved to fix this.** The coordinates are exactly what rev G
carried; all that changed is that they can now be checked. Fixing it is a
design decision — how much of it wants a welded joint and how much wants a
bolted fitting — and `analysis/frame.py` will re-check whatever comes back.

Related: the frame's own tube schedule comes to **48.4 lb** (27.5 cage, 13.2
boom, 7.7 gear) with **no gussets, no fittings and no weld metal**. The build
log CSV carries 31 + 5 + 4 = 40 lb for a cage that predates the pod-and-boom
architecture. Those two do not reconcile yet, and that is already on the list
as **workbook reconciliation**.

### Cowl height, which sets the forward view

The over-the-nose view is set by the engine, not the glazing. The cowl crown is
at z 47.3, **1.8 in above the pilot's eye**, so there is no depression angle
over the top of the nose at all — the pilot looks 2.9° *up* to clear it.

That crown allows the engine 7.3 in above the crank centreline, and **an
upright Hirth F-33 cylinder is taller than that.** So one of these has to give:

- the engine gets **clocked or tilted** to fit under the line;
- the **cowl grows**, and the forward view gets worse than the numbers in §26;
- the **thrustline drops**, which the propeller ground clearance in
  `trades/landing-gear.md` does not currently allow;
- the **eye rises**, which costs wing height and gives back the rev G drag win.

**Blocked on a physical measurement: an engine on the bench, with a tape on
it.** Nothing else settles this, and it decides the shape of the nose.

**The two weight statements disagree — PARKED, by owner decision.** The frame
and structure are being redrawn by hand, so reconciling a workbook against
superseded geometry buys nothing until that lands. Recorded, not being chased.
Re-open it when the redrawn frame has a weight.

The workbook Weight sheet omits the slats
(6 lb) and the cabane (6 lb) that `build-log/measured-weights.csv` carries:
honest EAB empty is ~308 lb, and the 103 strip is ~262 — **8 lb over the limit,
not 4 under**. Reconcile the workbook before quoting it. Full scrub and a
single-build path to ~253 lb in
[trades/weight-scrub-103.md](trades/weight-scrub-103.md).

**The engine, if the first build chases Part 103.** The scrub shows the airframe
can reach ~224 lb less power package, but the F-33 + belt (45 lb) cannot land
under 254 — a ~31 lb dual-spark paramotor-class engine (Polini Thor 250 DS
class, integral redrive) can, at ~253 lb and 23.9 kt stall. §15's 300-hr TBO
objection is mission-dependent at ~40 hr/yr. Verify actual engine weights on a
scale; keep the F-33 as the documented EAB upgrade path on the same mount.

**Airfoil section and its real CLmax.** Everything downstream hangs on it: stall
speed, flap geometry, spar depth, rib templates. Current numbers assume the Sky
Pup section at CLmax 1.4 clean, which is an assumption, not a measurement.
*First numbers now exist*: NeuralFoil at Re 1.12 M puts NACA 4412 at 2-D CLmax
1.61 (≈1.45 on the wing), so 1.4 is sound and slightly conservative. **4412 is the
working candidate** — see the addendum in
[trades/design-audit.md](trades/design-audit.md). Confirm against the true Sky Pup
section if it can be obtained.

**Dihedral and washout.** On a two-axis aircraft dihedral *is* roll control. Too
little means no authority, too much means dutch roll. Current placeholder is 4-6
degrees per side and 2-3 degrees washout. Needs the original design's actual
values or a defensible derivation.

**Flap geometry.** Chord fraction (25%c working number), span (~60% inboard),
hinge/false-spar detail, torque-tube diameter, Johnson-bar geometry and notch
loads. Plain flaps are far more forgiving than slats were — no
millimeter-critical gap — but the increment still wants verification:
NeuralFoil the flapped section at Re ~1M the same way the clean sections were
done. (Replaced the slat-geometry item: flaps-for-slats adopted, design-log
§21, with the quarter-scale stall demo as the escape clause.)

## Then, in order

- Full V-n diagram — **with the load basis re-set first**. The audit
  ([trades/design-audit.md](trades/design-audit.md)) shows fixed slats break the
  §12 stall-limit argument: g available at Vne is 5.74 at design weight, so
  either limit load rises to ~5.7 (+6–10 lb of cap, recommended) or Vne drops to
  ~62 mph — the tail-authority escape is closed: gate-3 trim analysis shows the
  elevator commands stall at every speed and CG. **Include the negative
  branch** (−1.9 g gust at Vc exists and no negative case does), and size
  fixed-mass fittings at the light-weight load factor
- **Pitch trim system — currently absent entirely, and required.** Elevator
  stick force is 2.5–2.7 lb across the envelope and the twist-grip decision
  put pitch and rudder on the same hand.
  [trades/borrowed-optimizations.md §3](trades/borrowed-optimizations.md)
  gives two options: **spring/bungee trim** at the stick base (lightest, no
  tab, no new flutter surface — AeroConversions' two-opposing-spring unit is
  $95, weight unpublished), or a **jackscrew-trimmable stabilizer**, which is
  heavier but solves trim, the incidence item below, and — critically —
  **preserves full elevator travel at every trim setting**, which a tab does
  not. That third property is not academic on an aircraft whose flare is its
  tightest control case. **Evaluate both in the gate-3 flap rerun** rather
  than defaulting to the lighter one; decide before the stick base is drawn
- **Adjustable stabilizer incidence — decide before the tail is welded.**
  The pending gate-3 flap rerun already expects to want ~1°; three shim
  positions at ±0.5° cost grams and turn a rebuild into a wrench. RV practice
  documents real post-first-flight corrections worth 2–3 kt of trim drag —
  a larger share of *excess power* on 22–31 hp than on their engines. On a
  welded cage with a single boom, retrofitting means cutting and re-welding.
  A jackscrew stabilizer (above) delivers this and the trim system together
- Spar cap taper schedule, web thickness, stiffener spacing
- **Cage member sizing — the architecture is decided, the tubes are not.**
  [trades/cockpit-cage.md](trades/cockpit-cage.md) fixes the rev F layout:
  all-steel, cage sta 30–96 on four longerons, **4130 3.50 × .049 boom welded
  to the aft frame** (the Kolb-fitting gate retires with the transition
  joint). Still open: longeron and diagonal sizes against the crash, gear and
  engine-mount reactions; **a rollover load basis, which no standard has been
  chosen for**; whether the front-spar pickups stay at ±8 in (wider reacts
  rolling moment better and fouls shoulders sooner — a mockup question); and
  the welded boom-to-cage cluster layout, still worth copying from Kolb even
  though the fitting is gone
- **Wing carry-through — cabane DELETED (rev G,
  [trades/enclosed-cockpit.md](trades/enclosed-cockpit.md)).** The wing sits
  on the cabin roof at chord line 58 and the sta 61.5 main hoop picks the
  front spar up directly at z=55. Remaining: **re-run `aero-model.py` for
  dihedral** — the high-wing pendulum arm drops 16% and this aircraft's roll
  control *is* dihedral, so expect +0.5–1°; and confirm the wing LE station
  still trims CG to 30% MAC with the seat moved forward 6 in for the recline
- **Egress — mechanism decided, execution unproven.** Positive film
  attachment plus **two mounted cutters** (design-log §25 addendum 2). What
  is left is physical: the **pre-slit and tab** at each panel's top corner
  (a shielded hook blade cannot puncture a taut membrane), bracket positions
  reachable **by feel and in gloves**, and a **timed proof test** from a
  fully assembled panel, in a harness, both sides. **~4–5 s** by the
  diagonal-cut-and-tear method, which clears the fire case
- **Glazing panel layout — a tear-arrest requirement, not a styling choice.**
  Film that tears at ~10 lbf for egress tears at ~10 lbf from a stone chip
  too, and cabin pressure keeps it primed. **The bead track is the ripstop:**
  divide the glazing at every cage member so a tear is arrested at the panel
  edge, and put the smallest panels low and forward in the spray zone. Do
  **not** substitute scrim-reinforced mesh — it would defeat the egress plan
- **Recline angle and seat station — mockup items.** 35° is the working
  number (head top z 49.5, hip sta 51); 30° eases entry and CG, 40° saves
  more drag. Also check head clearance (5.5 in on paper) with a helmet and
  the sling at full sag, and whether "open a door and sit in" actually works
  at the chosen sill height
- Gear geometry — **resolved** ([trades/landing-gear.md](trades/landing-gear.md)):
  mains sta 70.5 (15% MAC aft of CG), nose sta 32, track 56 in, seat 20 in AGL,
  8 fps / N=3 energy basis, 13×5.00-6 mains at 8–10 psi, tail skid. Remaining:
  leg curve/spring rate in gate 4, nose-leg spring detail, steering stops, and a
  456 lb drop test before first flight
- Tail sizing — **gate-3 analysis done** ([trades/trim-tail.md](trades/trim-tail.md)):
  keep 30 + 15 ft², i_t = −1.1°, elevator 45% chord ±25° (consider −30/+20),
  gearing ~4.5°/in, SM ~20–25%. Flare passes at forward CG in ground effect with
  23% margin. Remaining: **re-run with flap pitching moment and downwash**
  (flaps adopted, [trades/flaps.md](trades/flaps.md)) — full-flap flare at
  forward CG may saturate the elevator; expect a 25° landing notch or ~1° of
  tail incidence
- **Controls mechanization — DECIDED (design-log §21 + addendum,
  [trades/controls-mechanization.md](trades/controls-mechanization.md)):**
  one stick (elevator / lateral spoilerons / twist-grip rudder), left-hand
  symmetric spoiler lever (spring-return closed), rudder pedals deleted.
  Symmetric mode's payoff stands: ~720 → ~480 ft over the 50 ft trees.
  Remaining engineering, not decisions: **horn balance ~45% on the rudder**
  (the wrist-torque numbers do not close without it — size before the tail
  drawings freeze), grip centering/breakout behavior and brake-lever
  placement at the full-size seating mockup, no single-side hang-up from the
  symmetric path, Junco servo compatibility
- Cockpit geometry from actual seated dimensions — now for a **105–220 lb
  pilot range** (common-airframe §7): **mesh sling seat**
  ([trades/seat.md](trades/seat.md)) with lacing-tuned sag + adjustable
  footrest (the pedals are deleted with the twist-grip decision); mockup
  checks eye line and stick reach across the pilot range; sling **proof test
  to 1,920 lb** before first flight; crush-pad stroke clearance under the
  1-g sag point
- **Drag cleanup on the 80%** — open decision, the largest performance number
  left ([trades/borrowed-optimizations.md §2](trades/borrowed-optimizations.md)):
  wheel covers on the **mains only** (never the castoring nose — side area
  makes a weathervane), faired legs and cabane, and the footwell closeout the
  deleted pedals made free. ≈ −0.95 ft² of flat plate → **cruise L/D +15%,
  cruise power −13%** for ~1.6 lb, which the flaps/twist-grip/sling savings
  already cover. Decide with the pod shape, not after
- **Gap seals — seal the elevator; on the rudder, couple sealing to sizing.**
  NACA TN-632 measured a **sealed smaller surface matching an unsealed larger
  one at one-third the operating force**. First-order pass: a sealed rudder
  at cf/c ~0.29 (from 0.50) holds the same authority at **~57% less hinge
  moment** — twist-grip peak ~19 → ~8 in-lb, enough that **the 45% horn
  balance could become optional rather than mandatory**. Estimate only —
  but it means **rudder chord and sealing must be traded together, before
  the tail is drawn**, while both are still free. Friction, not hinge
  moment, is the real enemy: a teflon chafe strip under the seal is
  mandatory. Measure breakout with a spring scale on the built surfaces
- **Field rigging time as a numeric requirement** — proposed: one person, no
  helper, 15 minutes, no tools past a pin puller. Free if it constrains the
  wing-joint design now, expensive to retrofit after the joints are drawn
- Every fitting, detailed

**Glazing frame materials.**

The wraparound screen is not developable, so it is three panels per side on
frame rails — 303 in of tube, **2.6 lb** as drawn in 3/8 × .028 4130 against
the 1.0 lb the ledger carried. That 1.6 lb is what pushes the Part 103 aircraft
off a Lexan nose. Untried: aluminium extrusion, a smaller tube, or deleting the
phi = 95° rail if 0.060 sheet proves stiff enough to span unsupported.

## Verify before committing

- **The Part 103 engine's actual power rating — and more importantly its prop
  diameter.** The audit shows a direct-drive two-stroke is tip-speed limited to a
  35–42 in prop, giving ~96–114 lb static and a **240–340 ft ground roll**, not
  the ~160 ft claimed. The deleted 10 lb redrive is worth ~140 ft of runway.
  Either the 103 keeps a lightened redrive or the README's 103 field numbers get
  rewritten.
- **Spoileron aerodynamic close direction.** Tape a panel on and measure with a
  spring scale at 25 and 35 mph before trusting that airflow shuts it.
- **The ASI will lie during stall testing, and this project cannot afford
  that.** A Belite (Part 103) builder found his airspeed indicator failed
  completely at high alpha because the **pitot was micro-stalling** in
  oblique flow — 28–32.5 mph indicated against 29.1 calculated — fixed by
  bending the pitot into the local flow. This design chases a 23 kt stall
  with ~1 kt of regulatory margin: **plan pitot alignment and a calibration
  method (GPS three-leg or trailing cone) before first stall testing**, not
  after the numbers disagree.
- **Three weights nobody publishes, each blocking a decision** (see
  [trades/borrowed-optimizations.md](trades/borrowed-optimizations.md)): VG
  kit weight, GSC/Warp Drive ground-adjustable hub weight (**this one decides
  whether the 103 kit can use a re-pitchable prop**), and the
  AeroConversions trim system. All three want a phone call and a scale.
- **BRS package type against the pod-and-boom architecture.** §103.1 excludes
  the chute from the 254 lb empty weight, but an open cockpit with a single
  tail boom has nowhere to bury a softpack — which is why BRS catalogues
  vertical-launch (VLS) units specifically for the Kolb FireFly/FireStar.
  Confirm the BRS tray suits a VLS or canister unit before the cage is drawn.
- **Whether the 24 kt power-off stall is actually met in landing
  configuration.** Still a **legality item** — the stall gate caps gross at
  456 lb, which independently enforces the 254 lb empty limit. Much improved by
  the flaps decision: margin is now ~1.2 kt on a NeuralFoil-verified clean 1.45
  plus a textbook plain-flap increment, versus 0.1 kt on the unverified slatted
  1.8 it replaced. Verify the flapped section at Re ~1M, then on the
  quarter-scale model, then full-scale in Phase I.
- **Angle-of-attack annunciation — an EAB item, not a 103 one.**
  [trades/fly-by-wire.md §8](trades/fly-by-wire.md) concludes that telling the
  pilot the AoA delivers most of the benefit of active stall protection with
  **no actuator, no authority question and nothing that can fail inside the
  control circuit**, aimed at the accident category (LOC-I) behind ~40% of
  fatal GA accidents. Two caveats kept honest: **no controlled study
  quantifies accident-rate reduction from AoA indicators**, and a complete
  system is *"not quite two pounds"* — **the 103 kit cannot afford that**, so
  it rides on the EAB where the Junco already supplies display and plumbing.
  Resolve probe location and calibration **together with the pitot alignment
  item above** — both are air-data sensors in a flow field nobody has mapped,
  and the stall numbers depend on both
- **Battery capital cost, currently carried as $500/kWh in design-log §3.** That
  single figure decides the electric argument and has never been re-verified
  against current DIY 21700 pack prices. Check it before citing §3 again.
- **Whether the tail can give adequate roll authority unblown.** Gates any future
  pusher configuration, since the rudder is the roll control. The quarter-scale
  model cannot answer it — it is a full-scale, power-on question.
- **Ground-adjustable composite hub weights on a scale (EAB only).** The
  fleet currently buys two fixed wood props; a re-pitchable hub is what the
  ultralight world uses and what a two-engine, Phase-I-measured programme
  wants — but the 103's ~1 lb margin cannot carry the extra weight, so wood
  stays there regardless. See
  [trades/borrowed-optimizations.md §5](trades/borrowed-optimizations.md)
- **Propeller rpm, which decides blade count.** Two blades is comfortable to about
  1,750 rpm and cannot carry 1,600. Pick the rpm against an actual available belt
  redrive ratio, then the blade count follows. Do not pick blade count first.
- **The tip-speed noise exponent in §16.** The 8 dB claim reproduces only under a
  pressure ∝ V⁵ law; a power-based reading gives about 3.7 dB. Worth a measurement
  or a cited model before a redrive ratio is bought to chase it.
- **Wingtip shape.** Free L/D, and currently unspecified. Worth +2.9% off the
  assumed span efficiency and +9.5% against a square-cut tip — more than any
  winglet, at zero weight. Decide it with the tip bow, not after. Direction is
  moulded carbon caps to a copied Hoerner geometry — see
  [trades/wingtip-caps.md](trades/wingtip-caps.md).
- **Flap conversion weight on a scale.** The ~−1 lb net for flaps-for-slats
  (now adopted — design-log §21) is an estimate; hinges, torque tube, lever,
  and TE stiffening get weighed before the 253.2/275.7 lb ledger re-baselines.
- **Docile stall on the quarter-scale model, flaps up and down.** The
  flaps decision's escape clause: straight-ahead break, no wing drop, or the
  decision reverts to slats. **Vortex generators are now the first-line
  remedy ahead of that reversion**
  ([trades/borrowed-optimizations.md §1](trades/borrowed-optimizations.md)):
  ounces, bondable to Oratex, flight-line tunable, and aimed at exactly the
  outer-panel attached-flow property the slats used to provide. Keep the
  outer leading edge accessible and do not let the tip cap preclude them. (The slat-tip-termination item retired with the
  slats — the moulded tip cap is now unconstrained at the leading edge.)

## Not analysed anywhere, and should be

**Flutter.** No flutter analysis exists for this wing, tail, or control surfaces at
any configuration. §12 establishes the wing is stall-limited and therefore cannot
be aerodynamically overstressed, which is a load-factor argument and says nothing
about flutter. This gates Vne, mass balance on the elevator and rudder, and any
future decision to hang mass at the wingtips.

## Not technical, but decide early

**~~Drafting for yourself or for publication~~ — DECIDED (design-log §21):
for publication.** Full-size rib templates, a materials list with sizes and
sources, an assembly sequence; roughly triple the drafting effort, accepted.

**~~Whether the CAD is built to output cut files~~ — DECIDED (design-log §21):
yes.** 3D-first CAD from which DXF and STL fall out, per
[trades/digital-fabrication.md](trades/digital-fabrication.md). Published
plans ship cut files, which no other design in this class does.

**~~The covering system~~ — DECIDED (design-log §14 addendum): Oratex.**
75 hours and 8 lb bought for ~$1,400. The second-build caveat (covering is 27%
of aircraft #2 and Oratex pays its premium twice) was acknowledged and
accepted, because:

**~~Whether there is ever a second aircraft~~ — DEFERRED, deliberately
(design-log §21): decided after #1 proves out.** The first steel order is
sized for one aircraft. The DXF nesting is paid regardless, so a second 4130
set later costs only a repeat shop setup — that is the price of deferring, and
it is small. If #2 becomes real, ask a DAR early (major-portion rule and
repairman certificate apply per aircraft).

**Where Phase I happens — still open, and fine to hold until the build is well
along.** Phase I is the FAA's initial flight-test period for the EAB aircraft:
its operating limitations assign a test area (a radius and altitude block) in
which the required hours — typically 40 for a non-certified engine — must be
flown before passengers or ordinary cross-country flying. So the question
means: *which airport or large field hosts the initial test flying?* It needs
somewhere those hours can be flown without fighting airspace, and first flight
of a modified one-off does not belong in a backyard. (The pure-103 sister ship
has no formal Phase I, but its shakedown flying wants the same big field.)
Needs deciding before the EAB airworthiness application, not before drawing.

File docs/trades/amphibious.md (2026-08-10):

# Amphibious: What the Aventura Actually Does, and Why This Airframe Can't Follow It

**The question:** the Aventura UL appears to do everything this project wants
— in a tractor configuration — while also being amphibious. What are they
doing differently, and could the Nuthatch ever be converted?

## 1. Correcting the premise: the Aventura is a pusher, and it isn't 103

Two facts from the record change the framing:

- **The Aventura is a pusher.** The whole family (Bob Bailey design, 1995)
  are high-wing flying boats with the engine on a pylon above the hull and a
  **pusher propeller — specifically to keep the prop out of water spray**,
  which is the first structural fact of seaplane design. There is no tractor
  Aventura; a photo of the pylon engine from the wrong angle reads as tractor.
- **The "UL" is not Part 103.** The Aventura UL's empty weight is
  **328–390 lb** — 74 to 136 lb over the 254 cap. It is marketed
  ultralight-style but flies as a registered experimental (or as a fat
  ultralight, which this project's compliance-first rule forbids). It is not
  evidence that a 103 amphibian of this capability exists; it is evidence
  that even a company that wanted one badly couldn't hit the number.

## 2. What they do differently — and why each choice is water-driven

| Aventura choice | Why water forces it |
|---|---|
| Fiberglass planing hull *as* the fuselage | The hull is the float — no separate float weight, and fiberglass doesn't care about immersion |
| Engine on a pylon, pusher prop | Prop sits high and behind the cabin, above the bow spray that eats propellers at hump speed |
| Anodized aluminum tube + polyethylene tip floats | Every material survives dunking; nothing rusts or soaks |
| 40–65+ hp engines | Getting over the displacement drag hump needs roughly twice the thrust margin of a grass takeoff |
| Repositionable gear + retractable tailwheel | The amphibious part — wheels up for water, down for pavement |

The lesson isn't a trick to copy — it's that **every major configuration
decision flows from the water requirement**. Amphibian is not a feature you
add; it's the first requirement, and it picks the hull material, the engine
location, the prop direction, and the weight class before anything else gets
a vote.

## 3. Could the Nuthatch convert? The conflicts, in order of severity

**The prop kills it first.** The Nuthatch's tractor prop is at the nose with
the thrustline at 40 in and the 60-in disc's tips reaching down to **10 in
AGL** — a geometry chosen for grass stance and now protected by the rev D
raked nose gear. On floats, those tips sit perhaps 20 in above the water,
directly above the float bows, exactly where bow spray goes at hump speed.
Cubs survive on floats because their prop tips are ~3 ft up behind spray
rails; ours would be sandblasted (wood prop: destroyed) every takeoff. Fixing
it means raising the thrustline a foot or more or moving the engine to a
pylon — either way it is a different airplane.

**The stall gate leaves no weight for floats — almost.** Part 103 has a gift
here: §103.1 **excludes floats from the 254 lb empty weight**. But the 24 kt
stall gate still applies at gross, and that gate caps gross at 456 lb: 253 lb
aircraft + 170 lb pilot + fuel ≈ 453 lb. **Zero pounds available for the
~50–70 lb a float set weighs.** The one crack in this wall is the flaps trade
([trades/flaps.md](flaps.md)): Path B's CLmax ~1.95 raises the stall-limited
gross to ~494 lb — room for a light float set *on paper*. The prop-spray
problem stands regardless, which is why this stays a footnote and not a path.

**Power.** The hump drag of floats or a hull wants roughly twice the static
thrust margin of a grass roll. The 103 kit's ~22–28 hp paramotor-class engine
is sized to a 0.8 lb weight margin, not a water takeoff. The EAB's F-33 might
crawl over the hump on a calm day; "might" is not a design basis.

**Materials.** A wood-gusset airframe, birch ply, and 4130 steel all fly off
water in vintage practice — with marine sealing schedules and corrosion
programs that consume exactly the build-hour and weight budgets this project
spent elsewhere. Not impossible; expensive in the two currencies the project
has none of.

**Handling.** A rudder-rolls two-axis aircraft on the step in a crosswind,
with spoilerons for roll and no water rudder, is a handling experiment nobody
has run. The Aventura has three axes.

## 4. Verdict

**No amphibious conversion — recorded as rejected in the losers table.** The
Aventura succeeds *because* it was designed around water from the first line;
its configuration (hull fuselage, pylon pusher, waterproof materials, 40+ hp,
328+ lb) is the price of that requirement, and it pays the price by not being
Part 103. The Nuthatch made the opposite choices for the opposite mission —
low tractor prop for grass stance and crush protection, wood for cost and
buildability, 254 lb for legality — and each of those choices is
load-bearing.

If water flying ever becomes a real requirement: that is a second design (or
an Aventura-class kit purchase), not a Nuthatch modification. The honest
crumb this trade leaves behind: if flaps Path B is adopted, the stall-gate
arithmetic would no longer be the binding constraint against floats — the
propeller would be. It always was.

## 5. Follow-up: inflatable floats and a gear-for-floats swap

The refined proposal — high-pressure inflatable floats replacing the entire
wheel gear, plus "a structure that moves the prop out of the spray" — splits
into a half that genuinely works and a half that has no answer.

**The floats half works, and better than expected.** Inflatable floats are
proven ultralight equipment (the Full Lotus line has flown on ultralights for
decades — segmented low-pressure bladders in fabric; modern drop-stitch
"high-pressure" construction is the same idea, stiffer). And the accounting
is friendly: §103.1 excludes floats from empty weight, while the *removed*
wheel gear (~29.5 lb) comes off for real. Ledger: 253.2 − 29.5 gear
+ ~18 lb of float-attach structure (not excluded) = **241.7 lb for 103
purposes — legal with 12.3 lb of margin**, the most empty-weight room any
configuration in this project has ever had. Actual flying mass ≈ 302 lb with
a Full-Lotus-class 60 lb pair.

But the stall gate is merciless: gross ≈ 496 lb with pilot and fuel.
Slats at CLmax 1.8 stall at **24.9 kt — fails**. Flaps Path B at ~1.95
squeaks through at **23.9 kt** — the water version *requires* the
flaps-for-slats swap, and lands right back on a 0.1 kt razor edge.

**The prop half has no structure that fixes it.** The prop is bolted to the
engine; "moving the prop" means moving the engine or raising the whole
aircraft. The geometry that kills both:

- Floats sized for this gross (180% buoyancy → ~14 ft³, an 11 ft pair) put
  the step under the CG and the **bows ~16 in FORWARD of the prop plane**.
  The prop disc literally overhangs the bows — every wave crest and all of
  the bow spray root is inside the disc. A Cub survives on floats because its
  prop sits several feet *aft* of the bows and ~30 in up; ours is the
  forwardmost point of the aircraft.
- Raising the fuselage on a strut tower to get the tips 30 in above the
  waterline needs the thrustline at ~60 in — a **~30 in tower** that adds
  ~15–20 lb (not excluded), puts the CG ~50 in above the water (poor roll
  stability on the step, tip floats mandatory), destroys the low-entry
  stance, and *still* leaves the disc directly over the bows where hump
  spray fans upward.
- Power seals it: **19 lb/hp on the hump** with the 103 engine (seaplane
  practice wants ≤14); the EAB F-33 at ~14.8 is marginal on a calm day.

**Verdict unchanged, now with the accounting done:** the floats insight is
real and recorded — gear-for-floats plus the float exclusion makes the empty
weight *better*, and flaps Path B makes stall barely close. What cannot be
bought back is the nose propeller over the float bows. Getting the prop out
of the spray means getting the engine out of the nose, and the pusher trade
already showed where that balance divergence leads: a different airplane.
If a water sister-ship ever happens, it reuses this project's wing, tail,
and tooling on a new fuselage with a pylon engine — designed around water
from line one, like every amphibian that works.

## 6. What this does not settle

- Nothing structural — no provision is added to the airframe for this.
- The FAA's float-exclusion language (floats vs hull flotation) was not
  chased to a Chief Counsel interpretation, because the verdict doesn't
  turn on it.

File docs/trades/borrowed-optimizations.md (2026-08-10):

# Borrowed Optimizations: What the Ultralight World Does That This Design Hasn't

**The question:** looking at other ultralights, what else is worth stealing?
Script: `analysis/borrowed-optimizations.py`. Sources are marked
**[M]** measured / flight-test · **[B]** builder report, uncontrolled ·
**[V]** vendor marketing — the distinction matters more here than the numbers.

This project is already a borrowing machine — Sky Pup wing, Airbike steel,
Kolb boom, bicycle wheels and brakes, MTB coil-overs, glider Johnson bar,
sling seat. So the useful question is what is *left*. Eight items. Nothing
is adopted except §3, which is a hole rather than an upgrade.

---

## 1. Vortex generators — the flaps decision's real safety net

Design-log §10 justified slats on **roll control**, not stall speed:

> *"Slats specifically, rather than flaps, because there are no ailerons.
> Spoilerons need attached flow over the outer panel."*

§21 deleted the slats. The only mitigation on record is passive — washout,
inboard-only flaps, a model test — behind a 6 lb revert-to-slats escape
clause. VGs are the STOL world's *active* fix for that property.

**The precedent is nearly exact.** The Glasair GlaStar/Sportsman fits
**outboard delta VGs** for this reason and no other: *"when the airflow on
the outboard end of the wing can be made to stay attached, it greatly
improves the roll dampening,"* isolating the outboard section so it behaves
"like a low aspect ratio wing with higher stalling angles of attack" **[B]**.
Wainfan's sizing column states the general case: *"VGs placed upstream of
control surfaces allow increased deflection before flow separation,
improving control effectiveness"* **[M]**. StolSpeed's own placement
schedule tightens spacing to **60 mm for the first 900 mm from each tip**
and 90 mm inboard — tighter *specifically to protect the outer panel*, which
is exactly the spoileron region **[V, with test rationale]**.

**Sizing rules** (Wainfan **[M]**): height ≈ 1.2× local boundary-layer
thickness; BL is 1–2% of distance from the LE, so at 7–10% chord on a 50 in
chord this wing wants **~0.1–0.15 in** — commercial UL vanes are 12 mm
(0.47 in), deliberately oversized to tolerate sloppy placement. Co-rotating:
chord ≈ 4× height, spaced 5–6 heights. Must sit **upstream of the separation
point**. Drag penalty is normally offset downstream *except on laminar
sections* — and 4412 is not laminar, which is favourable here.

**Off the shelf:** StolSpeed **$133.95/80 or $178.85/120**, polycarbonate,
adhesive and templates included, experimental-only. Placement 7% chord
(*"from 8–12% I could detect no difference"*). Micro AeroDynamics is the
STC'd version at $695–1,450 — irrelevant to an experimental/103 aircraft.
**No vendor publishes a kit weight**; a few ounces is the honest estimate,
to be confirmed on a scale.

**The honest negatives, which matter more than the claims:**

- **VGs are not slats.** A CH701 owner who swapped slats for VGs measured
  **400 ft takeoff versus 200 ft with slats** **[B]** — the same nosewheel
  liftoff speed, but double the roll. If this aircraft ever needs the slats'
  *CLmax*, VGs will not supply it.
- **Many Kitfox owners report VGs did nothing at all** on their wing **[B]**.
  Results are wing- and placement-specific.
- The credible drag number is small either way: the FAA STC flight test
  found **1 kt top-speed loss at 12,000 ft full power, none at 75%** **[M]**.
- Stall-reduction claims of 4–9 mph are all **[B]** or **[V]**. Treat as
  unmeasured.
- **No documented case exists of VGs on a two-axis or spoiler-roll aircraft**
  used to preserve outer-panel flow for roll. Instrumenting this would be
  genuinely new data.

**Recommendation: hold the option open as a Phase I development item.** Cost
is zero — the only requirement is that the outer-panel leading edge stay
accessible and bondable, and that the moulded tip cap not preclude vanes.
The payoff is in the *escape clause*: today a wing drop on the model reverts
the airframe to slats; with VGs, the first response is $134 of polycarbonate
and slats become the fallback behind that.

## 2. Drag cleanup: the 80% the audit found and filed away

The audit: *"the smooth airframe is only f = 0.084 m² against the 0.45
carried — ~80% of the drag budget is cockpit, pilot, gear, rigging and
cooling."* It called that housekeeping and moved on, while the project spent
real effort on a tip shape worth 2.9%.

Housekeeping is **3.94 of 4.84 ft²**. Scenarios at 456 lb, 50 mph, e = 0.75:

| Case | f ft² | L/D max | L/D cruise | hp @ 50 | glide, mi/1,000 ft |
|---|---|---|---|---|---|
| Today | 4.84 | 10.81 | 10.06 | 6.04 | 2.05 |
| Wheel covers, mains only | 4.54 | 11.16 | 10.50 | 5.79 | 2.11 |
| + nose wheel + leg fairings | 4.29 | 11.48 | 10.91 | 5.58 | 2.17 |
| **+ footwell closeout, windscreen** | **3.89** | **12.06** | **11.62** | **5.23** | **2.28** |
| Aggressive, tuned | 3.49 | 12.73 | 12.43 | 4.89 | 2.41 |

**Target −0.95 ft²: cruise L/D +15%, cruise power −13%.**

**Frame the payoff as climb, not speed.** Drag *power* goes as V³, so at
50 mph the absolute mph gain is modest — but against 22–31 hp, drag saved is
a large fraction of *excess* power, and excess power is climb. Do not import
RV-world expectations: a fairing worth 0.1 kt at 100 kt is worth 5.5 kt at
250 kt **[M]**, and the +6 to +19 mph figures quoted for wheel pants and leg
fairings are all from 160–200 mph aircraft.

Three specifics, each sourced and each with a caveat:

- **Streamline the exposed tubing — the best-supported item.** KITPLANES
  gives **~1 mph of cruise per 4 ft of round tubing streamlined**, with one
  builder gaining **7 mph from ~28 ft on an experimental ultralight**
  **[B]**. A cylinder runs **Cd ≈ 1.1** at this Reynolds number against
  ~0.05–0.1 faired — a 10–20× reduction, with gear legs called out as the
  worst offenders. Gear legs, cabane, and boom junctions are the targets.
- **Wheel covers on the mains only.** Bicycle disc covers cost ounces. **Not
  the nose** — it castors, and side area on a castoring wheel in a crosswind
  makes a weathervane of the one component already carrying a shimmy-damper
  requirement. Note also that the Alaska STOL community *removes* pants for
  grass and mud; treat covers as removable, not permanent.
- **Footwell closeout and windscreen.** *Newly free*: deleting the rudder
  pedals emptied the footwell and the rev E pod is non-structural, so shape
  can serve pressure recovery instead of clearance.

**What not to copy:** the Quicksilver nose bubble buys **+7 mph for +15 lb**
at $415 **[V]**. On a 254 lb limit that is disqualifying. The 3–5 lb partial
fairing is the version this aircraft can afford.

**Weight ≈ 1.6 lb, already paid for** by the ~4.8 lb §21 freed (flaps −1,
twist grip −2, sling −1.8). Spending it here beats letting it evaporate.

## 3. There is no pitch trim system. Anywhere.

**A hole, not an optimization.** `trim-tail.md` covers *aerodynamic* trim and
fixes tail incidence at −1.1°; the controls ledger is stick 7 lb, pedals 5
(deleted), spoileron rig 4. Nothing relieves stick force in flight.

| Condition | Deflection | HM, in-lb | Stick force |
|---|---|---|---|
| Cruise 50 mph, 1 g | 3.0° | 34 | 2.6 lb |
| Slow 35 mph, 1 g | 6.0° | 33 | 2.6 lb |
| Climb 40 mph full power | 4.5° | 32 | 2.5 lb |
| Vne 62 descent | 2.0° | 34 | 2.7 lb |

2.5–2.7 lb held continuously needs trim on a 2–3 hour aircraft — and more so
here, because §21's twist grip put pitch and rudder on **the same hand**, so
the force is held by the wrist that must also make precise yaw inputs.

A forum objection exists — *"a Part 103 UL has such a narrow operating range
that adjustable trim may be pointless"* **[B]** — and **it does not apply**:
this envelope runs 23 kt stall to 54 kt, and the pilot is 35–45% of gross
across a 105–200 lb range, which moves CG far more than fuel burn does.

**Two options, and the second is more interesting than it first looks:**

1. **Spring/bungee trim at the stick base** — the ultralight standard. The
   AeroConversions system (a trim wheel tensioning **two opposing springs**,
   built for Y-tails that cannot take a tab) is **$95**, roughly
   **2–3 mph of trim speed per turn** on a Sonex **[V]**; weight not
   published. No tab, no hinge, no new flutter surface. Lightest and
   simplest.
2. **Jackscrew-trimmable stabilizer** (Piper J-3 family; a Kitfox option) —
   heavier and more cables, but it **solves three problems with one
   mechanism**: in-flight trim, the ground-adjustable incidence of §6, and —
   critically — it **preserves full elevator travel at every trim setting**,
   which a tab does not. One builder reported his jackscrew installation
   weighed *less* than the fixed one because it replaced the stabilizer
   cross tube **[B]**.

Point 2's third property is not academic here: the flare is this aircraft's
tightest control case (−19.3° of −25° before flaps, and the gate-3 flap
rerun expects it to get tighter). A trim system that eats elevator authority
is spending exactly the wrong currency. **Recommend evaluating the
trimmable stabilizer against spring trim in the gate-3 rerun**, rather than
defaulting to the spring because it is lighter.

## 4. Gap seals — with the real numbers, and the real enemy

My first pass had this backwards. The canonical measurement is **NACA
TN-632**, flight-tested on a Fairchild 22 **[M]**:

- Sealing gained **~20%** effectiveness on 0.18c ailerons, **~33%** on 0.09c
  — *smaller surfaces benefit more*.
- **The design lesson:** sealed 0.09c ailerons matched the effectiveness of
  unsealed 0.18c ailerons **while requiring about one-third the operating
  force.**

So the right question is not "does sealing cost hinge moment" but **"can a
sealed smaller surface do the same job for less force?"** — which is a live
question for a rudder on a wrist-torque budget, not a closed one.

A first-order pass says the answer may be yes, by a lot. Holding yaw
authority constant with ideal thin-airfoil effectiveness and a mid-range
seal factor, the rudder goes from **cf/c 0.50 to ~0.29**, and hinge moment —
seal penalty already included — falls **~57%**:

| | As drawn | Sealed and shrunk |
|---|---|---|
| Rudder chord / VT chord | 0.50 | ~0.29 |
| Effectiveness (τ, × seal) | 0.818 | 0.818 |
| Twist-grip peak, 35 mph full | ~19 in-lb | **~8 in-lb** |

If that survives a real analysis it does more than save effort: it could
**relax the 45% horn balance the twist-grip scheme currently depends on** —
turning a hard requirement into a choice. Treat the number as an estimate
(ideal τ, assumed seal factors) and **do not size on it** — the finding is
that the question must be asked *before the tail is drawn*, when both
variables are still free.

**The real downside is friction, not hinge moment.** Sailplane practice
**[B]** builds a three-layer stack — double-sided tape to the fixed surface,
a pre-curved **mylar** strip bridging the gap, capping tape over its leading
edge — and applies **teflon glass tape to the moving surface as a chafe
strip, specifically to stop a friction-driven rise in control forces.** For a
twist-grip rudder, breakout friction is the one thing that must not creep
in: **the teflon strip is mandatory, not optional.**

Recommendations: **seal the elevator** (authority for the flap flare, and
§3's trim absorbs the force). **On the rudder, treat sealing as coupled to
sizing** — sealed-and-smaller may beat unsealed-and-larger on wrist torque,
per TN-632 — and measure breakout force on the built surface with a spring
scale, alongside the spoileron-close-direction test already scheduled.
Note that **none of this applies to the spoilerons**, which are not hinged
trailing-edge surfaces. Vendor claims of *"roll rate close to 100% higher"*
are **[V]** and unsupported by the NACA data.

## 5. Ground-adjustable propeller — and it need not cost weight

**My EAB-only conclusion was wrong, on one fact:** **GSC Systems makes a
ground-adjustable *wood* propeller** (Tech II/III) — CNC 6061-T6 hub,
laminated maple blades with composite-encapsulated roots, **36–72 in in 2 in
increments** (60 in is stock), and **individually replaceable blades**. That
removes the composite-hub weight penalty that ruled the 103 kit out, and it
directly obsoletes the plan to buy **two different fixed wood props**.

Three supporting findings:

- **Props buy climb, not cruise.** A back-to-back test of nine props
  (EProp, Bolly, Kiev, Warp Drive, Meglin and others) **[M]** found static
  thrust spanning **155–196 kg** and climb **910–1,034 fpm**, while **cruise
  at equal manifold pressure fell within 1–2 kt across all of them** —
  concluding that big cruise claims usually reflect *applying more power*,
  not a better prop. For an aircraft whose binding requirement is a 200 ft
  takeoff roll, this says optimize pitch for the ground roll and ignore
  cruise marketing.
- **Pitch is how you manage a two-stroke's EGT** — *"too much pitch and low
  EGTs, too little and you have high EGTs"* **[B]**. A fixed prop makes that
  a jetting problem instead.
- **Pitch is the cleanest way to set Vh for §103.1(e)(3).** The 103 kit
  already plans a "compliance pitch" prop; ground-adjustable makes the
  compliance setting a wrench rather than a second purchase.

**Blocking fact: GSC publishes no weight or price** (nor does Warp Drive
credibly — ~7–8 lb for a 2-blade is weakly sourced). **Call GSC and Warp
Drive directly; this single number decides the prop question**, because the
103 kit has ~1 lb of margin. If GSC's hub costs more than ~1 lb over a fixed
wood prop, the EAB-only split stands after all.

## 6. Adjustable stabilizer incidence — decide before the tail is welded

Van's RV sets incidence with **shims at the forward spar attach**, and real
post-first-flight corrections are documented: an RV-6A added a second 1/8 in
shim at ~50 hours, moving cruise trim from 3/4 travel to 1/4 and **gaining
2–3 kt**; an RV-9 builder went from 3/16 to 1/4 in shims and **halved** the
cruise trim deflection **[B]**.

An incidence error shows up as permanently deflected trim, which is
permanent trim drag — 2–3 kt out of ~150 on an RV, but a much larger share
of *excess power* on 22–31 hp. The pending gate-3 flap rerun already expects
to want ~1°.

**On a welded cage with a single aluminum boom, retrofitting this means
cutting and re-welding.** It is nearly free at build time and expensive
after. Provide a shim stack or eccentric bushing at the stabilizer front
attach — or adopt §3's jackscrew stabilizer, which delivers this and the
trim system together.

## 7. Field rigging deserves to be a requirement

Sourced one-person times: **Kolb FireFly ~15 min** (wings fold rearward on
universal joints and never detach; struts stay attached at the wing end,
halving the pin count) **[V/B]**; **Aerolite 103** ~20 min off / 30 on
**[V]**; **Sonex** 15 min with two people factory, ~30 min for builders
**[V/B]**.

The features that actually buy speed: **controls stay connected through the
joint** (the slow, error-prone, fatal-if-wrong step), fold rather than
remove, clevis pins with rings instead of bolts, and **wheeled wing dollies
with adjustable stands** so one person never holds a panel.

**The honest caveat for this aircraft:** every fast-rigging example above is
strut-braced. A 31 ft **cantilever** wing has root joints carrying full wing
bending — large pins in double shear plus separate drag/anti-drag fittings —
and panels that are heavy and awkward solo. **Rolling dollies are not a
convenience here, they are the mechanism.**

One dimension check, cheap and worth doing now: the research flagged that a
16 ft trailer will not swallow a 15.5 ft panel. This design is **three**
piece with ~11.5 ft outer panels (§6), so it clears — but confirm the centre
section and dolly footprint against the 16 ft box before the joints are
drawn.

**Recommendation: adopt a numeric requirement** — one person, no helper,
15 minutes, no tools past a pin puller — so it constrains the joint design
rather than being discovered after.

## 8. The Quicksilver precedent — read this one twice

The most directly cautionary evidence found, on an aircraft of nearly
identical size (28 ft span, 156 ft², 250 lb empty, 24 mph stall, 50 mph
cruise). Eipper's MX went two-axis with heavy dihedral; pilots wanted roll
authority; **Eipper added spoilerons, which were "only minimally
effective"**; the next generation got **true ailerons**, which "finally
provided full roll authority" **[B]**.

That is this project's core control decision, tried at this scale, and found
wanting. It belongs in the record.

**The counter-evidence is stronger, and the distinction is the point.**
Kohlman's flight tests of spoiler roll control on three light aircraft (SAE
770441) **[M]** found *"excellent roll characteristics,"* **yaw coupling
with roll input virtually eliminated** (a real prize when the rudder is
already doing double duty), roll rates that **stay high with flaps deployed
at low speed**, and *"very mild nonlinearities"* with **no deadband or lag**
— flatly contradicting the usual folklore.

The critical caveat: Kohlman's aircraft were **designed around spoilers**,
where Quicksilver's were **added to a wing that was not**. This design is in
the first category, which is the reason to expect the good outcome rather
than the bad one — but it converts the quarter-scale model's roll work from
a formality into the item that decides whether the configuration works. The
audit's existing rudder-roll numbers (17–23°/s, ~2 s to 30° bank) are the
prediction; Quicksilver is what failure looks like.

**A gift in the same history:** on the MX, *"the pilot could deploy both
spoilerons at the same time by depressing the rudder pedals. This killed
lift on the wings and allowed the aircraft to get into very short
runways"* **[B]**. The symmetric spoiler mode adopted in §21 is not novel —
it is recovered practice from the closest relative this configuration has.

A structural note worth carrying: spoilers put **almost no torsion into the
wing**, which on a 31 ft cantilever *wood* wing — where torsional stiffness
drives D-tube and spar weight — is a structural argument for the
configuration, not merely an aerodynamic one.

---

## Bookkeeping catch: the headline L/D is right for the wrong reasons

| Effect | L/D change |
|---|---|
| Slats deleted by the flaps decision (CD0 0.0430 → 0.0373) | **+7.4%** |
| Audit's Oswald correction (e 0.85 → 0.75) | **−6.1%** |
| **Net** | **10.80 vs the 10.7 quoted** |

The README's 10.7 survives only because the flaps decision handed back
almost exactly what the Oswald correction took. **Fixing either without the
other introduces a real error.**

## Checked and cleared: the Part 103 stall alarm

The research flagged that 23 kt × √(525/456) = 24.7 kt "busts the Part 103
stall limit." **It does not** — it conflates the two grosses. 456 lb *is*
the Part 103 gross, set by the 24 kt gate; **525 lb is the EAB gross** and
the gear/fitting structural case, and an EAB aircraft is not subject to
§103.1(e)(4) at all. Recorded because the arithmetic looks alarming and will
be re-derived by someone else eventually.

## Two new verification items this survey produced

- **The airspeed indicator will lie during stall testing.** A Belite
  (Part 103) builder found his **ASI failed completely at high alpha because
  the pitot was micro-stalling** on oblique flow — measured 28–32.5 mph
  against 29.1 calculated — fixed by bending the pitot down into the local
  flow **[B]**. This project is chasing a **23 kt stall with ~1 kt of
  regulatory margin**: that number cannot be verified with a misaligned
  pitot. Plan pitot alignment and a calibration method (GPS three-leg or
  trailing cone) *before* first stall testing.
- **BRS installation on a pod-and-boom airframe.** §103.1 excludes the
  chute from the 254 lb empty weight (Kolb cites a 24 lb allowance on a
  254 lb FireFly), but an open cockpit with a single tail boom **has nowhere
  to bury a softpack** — which is why BRS catalogues **VLS (vertical launch,
  top-mounted)** units specifically for the FireFly and FireStar. Ultralight
  systems run **$6,206–7,784**. The rev E architecture should confirm its
  BRS tray suits a VLS or canister unit, not a softpack.

## What this does not settle

- Every drag number is an **estimate against a back-solved model**; the
  split between pilot, gear and cooling is indicative. Phase I glide
  measurement is what makes it real. **No component drag breakdown for
  open-cockpit ultralights exists in accessible literature** — the "pilot is
  the biggest drag item" claim is repeated everywhere and measured nowhere.
- **Three weights nobody publishes**, each blocking a decision: VG kits,
  GSC/Warp Drive hubs, and the AeroConversions trim system. All three want a
  phone call and a scale.
- VG placement and benefit on *this* wing — flight-line tuning, and a real
  chance to generate data that does not currently exist.
- Gap-seal breakout force on the built surfaces, by spring scale.
- Whether wheel covers survive wet grass without packing mud.

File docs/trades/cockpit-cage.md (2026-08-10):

# The Cockpit Cage, an All-Steel Airframe, and Where the Wing Attaches

**The proposal:** a steel tube cage around the pilot; and since the cage is
steel anyway, make the boom and tail steel too, with fabric over everything —
designed to be genuinely aerodynamic and to attach the wing directly to the
cage. Script: `analysis/cage-design.py`. Drawing: `drawings/sheets/ST-001.png`.

**Adopted as rev F**, including the part that reverses a decision made two
revisions ago. Rev E chose a **6061-T6 aluminium** boom on weight. Re-run
fairly, that margin is much smaller than it looked, and steel wins on grounds
rev E never scored.

## 1. The steel boom, re-opened honestly

Required: **38,034 in-lb ultimate** over the 86 in from cage to tail post.

| Tube | S in³ | Fb ksi | M allow | Margin | Weight |
|---|---|---|---|---|---|
| 6061-T6 5.00 × .065 *(rev E)* | 1.227 | 39.0 | 47,867 | +26% | **8.5 lb** |
| **4130 3.50 × .049** | 0.452 | 95.0 | 42,940 | **+13%** | **12.9 lb** |
| 4130 4.00 × .035 | 0.428 | 76.1 | 32,613 | −14% | fails |
| 4130 4.50 × .035 | 0.544 | 67.7 | 36,797 | −3% | fails |
| 4130 5.00 × .035 | 0.673 | 60.9 | 40,981 | +8% | 13.3 lb |
| 4130 4.00 × .049 | 0.593 | 95.0 | 56,382 | +48% | 14.8 lb |

**Raw steel penalty: +4.4 lb** — not the doubling one might expect, and the
reason is worth understanding. **A thin-wall boom is limited by local
buckling, not by material strength.** Steel's stiffness is 2.9× aluminium's
and its density is 2.89× — those very nearly cancel, which is exactly why
both materials appear on real booms. Steel never gets to use its 95 ksi here;
at these wall thicknesses it buckles first. (The one exception, 4130 4.00 ×
.049, *is* material-limited — and pays 14.8 lb for a margin nobody needs.)

### What steel buys back

| Credit | lb |
|---|---|
| Boom-root fitting: a welded cluster instead of a machined, bonded/bolted sleeve into the steel cage | −1.2 |
| Tail-post fittings: welded instead of bolted brackets | −0.8 |
| No dissimilar-metal isolation or galvanic detail | −0.2 |

**Net steel penalty: +2.2 lb.**

Both of those fittings were flagged in the rev E trade as *"copy
dimension-for-dimension from a Kolb installation"* — precisely because an
aluminium-boom-to-steel-cage joint is the fiddly, unfamiliar part of the
design. **All-steel deletes that joint entirely.** The boom root becomes four
welds into the aft cage frame: the same skill, the same jig, the same filler
rod already required for the cage. The gate that said "copy Kolb's fittings"
retires with it.

### The argument nobody had made yet: fatigue

**4130 has a true endurance limit** — roughly 45–50% of Ftu — below which
life is effectively infinite. **6061-T6 has none.** Every load cycle consumes
life, forever, and the S-N curve keeps falling.

This boom carries a two-stroke's vibration spectrum plus tail buffet at the
end of an 86 in cantilever. Kolb has flown aluminium booms for forty years,
so this is not disqualifying — but an aluminium boom is a **fatigue-managed
part** needing a defined inspection interval, and a correctly sized steel one
is not. On an aircraft whose flutter analysis does not yet exist, and whose
owner wants an airframe that lasts, that asymmetry is worth 2.2 lb.

**Decision: 4130 3.50 × .049 boom, welded to the cage.** Same load basis,
+13% margin, one material, one process, no transition joint.

## 2. The cage, and the convergence that should set it

Cage runs **sta 30 to 96**, four longerons, welded 4130.

| Station | Frame | Job |
|---|---|---|
| 30 | Nose bow | Crush structure aft of the rev D gear bay; forward cage closure |
| **61.5** | **Main hoop** | **Rollover + front spar carry-through + at the CG** |
| 80.5 | Rear frame | Rear spar pickup, seat back, harness anchors |
| 96 | Aft frame | Boom pickup, four welds |

**The convergence is the whole design.** Three independent requirements land
within 2.5 inches of each other:

- **CG (30% MAC): sta 63.0**
- **Front spar (25% chord): sta 60.5**
- **Rollover hoop, clearing the pilot's head: sta ~62**

They should therefore be **one frame**, and that single heavy hoop at
sta 61.5 then does three jobs at once:

1. Carries **88% of wing lift** straight into the cage over the shortest
   possible path.
2. Is the rollover structure over the pilot's head.
3. Sits **at the CG**, so wing lift feeds essentially **no pitching couple**
   into the fuselage and the cabane carries no fore-and-aft kick.

That third point is the one that matters structurally: a wing pickup offset
from the CG has to react a moment through the longerons, which is how
fuselages get heavy. Putting the pickup on the CG deletes the moment instead
of carrying it.

The rear frame at sta 80.5 is then genuinely light — it sees only 434 lb
ultimate — so it can double as the seat-back frame and harness anchor without
growing.
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

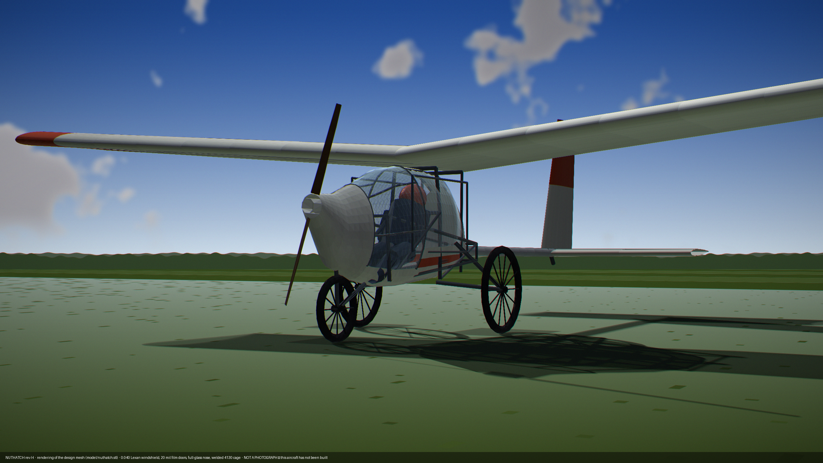
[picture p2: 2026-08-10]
drawings/renders/hero-ramp.png

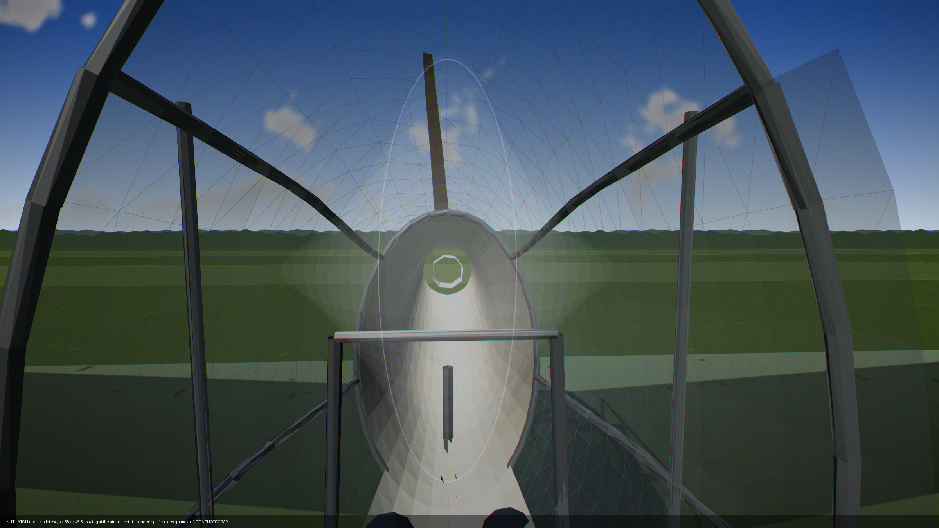
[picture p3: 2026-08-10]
drawings/renders/hero-eye.png

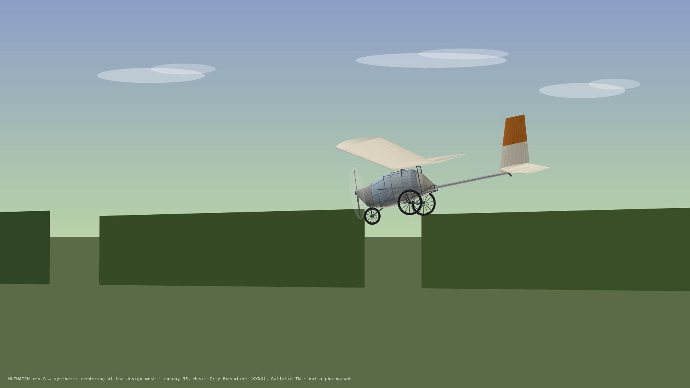
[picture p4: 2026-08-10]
drawings/renders/kxnx-takeoff-2.png

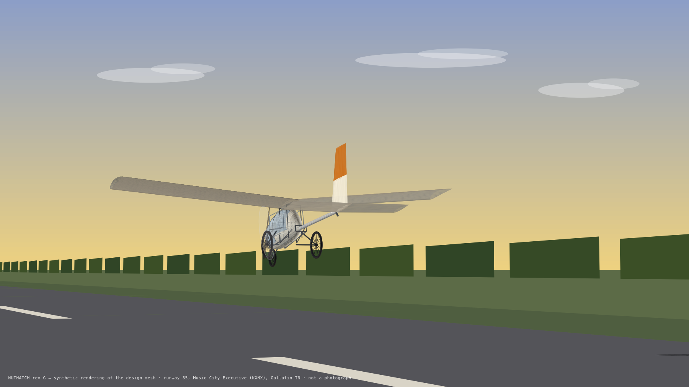
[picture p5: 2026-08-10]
drawings/renders/kxnx-takeoff-1.png

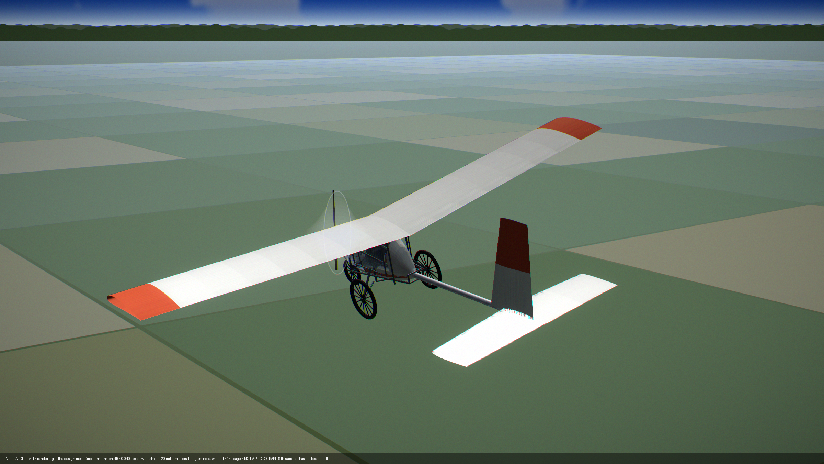
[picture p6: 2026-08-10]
drawings/renders/hero-air.png

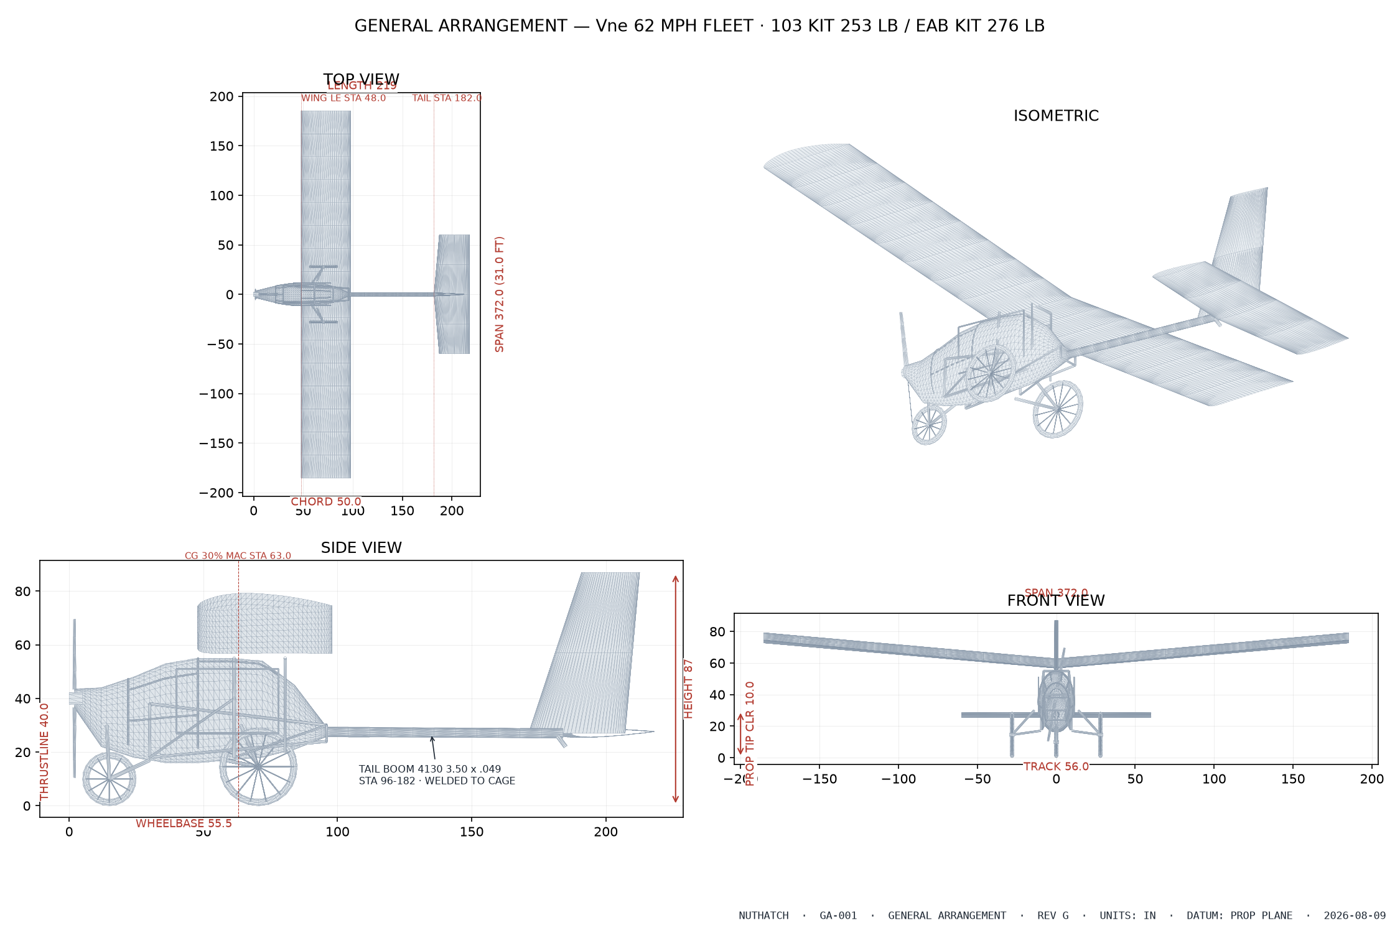
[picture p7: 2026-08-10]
drawings/sheets/GA-001.png

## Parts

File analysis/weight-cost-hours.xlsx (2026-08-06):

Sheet: Weight
Sky Pup / Airbike Derivative - Weight and Balance
130 sq ft 3-piece wood wing, welded 4130 fuselage, 2-axis + spoilerons, tricycle gear, Hirth F-33.
Datum = prop plane. Wing LE sta 48, chord 50 in. Blue=estimate, yellow=type measured, it overrides.
Column '103 Strip' is the weight of that item in the Part 103 configuration. 0 means deleted.
Item | Group | Est lb | Measured lb | Used lb | Station | Moment | 103 Strip lb
Spar: 1.25 sch40 caps, wrapped web, rivets | Wing | 22.0 |  | 22.0 | 72 | 1584 | 22.0
Ribs, 31 ea, Douglas fir truss | Wing | 8.0 |  | 8.0 | 74 | 592 | 8.0
D-tube leading edge, 1/16 birch ply | Wing | 12.0 |  | 12.0 | 60 | 720 | 12.0
Rear spar / spoileron hinge spar | Wing | 5.0 |  | 5.0 | 86 | 430 | 5.0
Trailing edge stock | Wing | 3.0 |  | 3.0 | 100 | 300 | 3.0
Joint rods, sleeves, 8 bolts | Wing | 7.0 |  | 7.0 | 68 | 476 | 7.0
Spoilerons, hinges, return springs | Wing | 4.0 |  | 4.0 | 82 | 328 | 4.0
Fabric and finish, 260 sq ft | Wing | 14.0 |  | 14.0 | 74 | 1036 | 11.5
Wing misc hardware | Wing | 4.0 |  | 4.0 | 72 | 288 | 4.0
4130 longerons, verticals, diagonals | Fuselage | 28.0 |  | 28.0 | 85 | 2380 | 28.0
Cluster gussets and brackets | Fuselage | 3.0 |  | 3.0 | 80 | 240 | 3.0
Structural nose bow | Fuselage | 4.0 |  | 4.0 | 30 | 120 | 4.0
Rollover hoop | Fuselage | 4.0 |  | 4.0 | 54 | 216 | 4.0
Seat structure and Confor foam | Fuselage | 6.0 |  | 6.0 | 58 | 348 | 6.0
5-point harness | Fuselage | 4.0 |  | 4.0 | 58 | 232 | 4.0
Turtledeck formers | Fuselage | 3.0 |  | 3.0 | 110 | 330 | 3.0
Fuselage fabric and finish, 100 sq ft | Fuselage | 6.0 |  | 6.0 | 85 | 510 | 5.0
Windshield | Fuselage | 4.0 |  | 4.0 | 42 | 168 | 0.0
Horizontal stab and elevator, 30 sq ft | Tail | 12.0 |  | 12.0 | 184 | 2208 | 11.0
Vertical fin and rudder, 15 sq ft | Tail | 6.0 |  | 6.0 | 180 | 1080 | 5.5
Tail attach fittings | Tail | 2.0 |  | 2.0 | 182 | 364 | 2.0
Sprung 4130 main gear legs | Gear | 8.0 |  | 8.0 | 80 | 640 | 7.0
Main wheels and tires | Gear | 12.0 |  | 12.0 | 80 | 960 | 8.0
Bicycle hydraulic brakes and adapters | Gear | 3.0 |  | 3.0 | 80 | 240 | 3.0
Nose gear leg, wheel, steering | Gear | 12.0 |  | 12.0 | 36 | 432 | 9.0
Gear mounts and fittings | Gear | 3.0 |  | 3.0 | 60 | 180 | 3.0
Stick, elevator run, bellcranks | Controls | 7.0 |  | 7.0 | 60 | 420 | 7.0
Rudder pedals and cables | Controls | 5.0 |  | 5.0 | 100 | 500 | 5.0
Spoileron cables, pulleys, springs | Controls | 4.0 |  | 4.0 | 74 | 296 | 4.0
Hirth F-33, 28 hp, incl exhaust | Power | 35.0 |  | 35.0 | 14 | 490 | 28.0
Belt reduction drive | Power | 10.0 |  | 10.0 | 10 | 100 | 0.0
Propeller, wood, 60 in | Power | 8.0 |  | 8.0 | 2 | 16 | 7.0
Engine mount | Power | 5.0 |  | 5.0 | 18 | 90 | 4.0
Fuel tank, lines, shutoff | Power | 8.0 |  | 8.0 | 50 | 400 | 5.0
Junco, tablet, mount | Systems | 4.0 |  | 4.0 | 44 | 176 | 0.0
Wiring, switches, master | Systems | 2.0 |  | 2.0 | 50 | 100 | 0.0
BRS hard points and bridle channel | Systems | 3.0 |  | 3.0 | 70 | 210 | 3.0
AN hardware, paint, placards | Systems | 6.0 |  | 6.0 | 80 | 480 | 5.0
EMPTY WEIGHT |  |  |  | 296.0 | 66.5 | 19680 | 250.0
Empty CG is in the Station column. Part 103 limit is 254 lb.
BY GROUP
Group | lb | % of empty | 103 lb
Wing | 79.0 | 26.7% | 76.5
Fuselage | 62.0 | 20.9% | 57.0
Tail | 20.0 | 6.8% | 18.5
Gear | 38.0 | 12.8% | 30.0
Controls | 16.0 | 5.4% | 16.0
Power | 66.0 | 22.3% | 44.0
Systems | 15.0 | 5.1% | 8.0
LOADED CG CASES
Pilot station | 58
Fuel station | 50
Wing LE station | 48 | Target CG 25-35% MAC. Move this to trim the CG.
Case | Pilot lb | Fuel lb | Gross lb | CG in | % MAC
Allen, full fuel | 170 | 30 | 496.0 | 62.6 | 29.2%
Allen, no fuel | 170 | 0 | 466.0 | 63.4 | 30.8%
220 lb pilot | 220 | 30 | 546.0 | 62.2 | 28.3%
130 lb pilot | 130 | 30 | 456.0 | 63.0 | 30.0%

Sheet: Cost
Bill of Materials
OnlineMetals for 6061 and 4130, lumber yard for select vertical grain Douglas fir.
Item | Category | Est $ | Actual $ | Used $ | Note
1.25 sch40 6061-T6 spar caps, 62 ft | Wing | $650 |  | $650 | Verify 6061-T6, not 6063
0.020 6061 web sheet plus rivets | Wing | $200 |  | $200
Douglas fir, truss ribs and wing structure | Wing | $200 |  | $200 | Lumber yard, VG, 6+ rings/in
1/16 birch ply, D-tube | Wing | $180 |  | $180
Rear spar tube and trailing edge | Wing | $150 |  | $150
Joint rods, sleeves, AN bolts | Wing | $220 |  | $220 | Machine shop stock
Spoileron hinges, springs, cable | Wing | $180 |  | $180
4130 tube, fuselage | Fuselage | $500 |  | $500
4130 tube, tail surfaces | Fuselage | $200 |  | $200
Welding gas and filler | Fuselage | $100 |  | $100
Windshield polycarbonate | Fuselage | $150 |  | $150
Seat, Confor foam, 5-point harness | Fuselage | $350 |  | $350
Stewart Systems fabric and finish, 430 sq ft | Covering | $1400 |  | $1400 | Waterborne
Hirth F-33 with belt redrive | Power | $4200 |  | $4200 | Used runs ~2500. See options below
Propeller, wood, 60 in | Power | $350 |  | $350
Fuel tank, lines, shutoff, filter | Power | $200 |  | $200
Main wheels and tires, no brakes | Gear | $250 |  | $250
Bicycle hydraulic disc brakes x2 | Gear | $250 |  | $250 | DH grade, 203mm rotors
Rotor-to-hub adapters, material | Gear | $50 |  | $50 | Machine yourself
Nose gear, wheel, steering linkage | Gear | $400 |  | $400
4130 sprung gear leg stock | Gear | $120 |  | $120
Cables, pulleys, rod ends, stick, pedals | Controls | $500 |  | $500
AN hardware, bolts, nuts, washers | Hardware | $500 |  | $500 | Always underestimated
Junco, tablet, mount | Systems | $350 |  | $350
BRS hard points and doublers | Systems | $60 |  | $60 | No chute installed
Epoxy, glue, abrasives, consumables | Consumables | $350 |  | $350
Weld jig, wing jig, misc tooling | Tooling | $200 |  | $200
DAR inspection and N-number | Cert | $755 |  | $755
MATERIALS SUBTOTAL |  |  |  | $13015
Contingency |  | 30% |  | $3904.5
TOTAL |  |  |  | $16919.5
ENGINE OPTIONS - the only line that decides the $15k target
Option | Engine $ | Total $ | Weight lb | Ignition
Hirth F-33, new | $4200 | $16919.5 | 45 | Dual CDI
Hirth F-33, used | $2500 | $14709.5 | 45 | Dual CDI
Rotax 277, used | $1200 | $13019.5 | 62 | Single

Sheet: Hours
Build Hours
Design time excluded. Sky Pup baseline is 450-600 hr. Your experience factor is applied below.
Task | Phase | Raw hr | Actual hr | Used hr | Note
Weld jig and fuselage structure | Fuselage | 130 |  | 130 | Your MIG/TIG work
Nose bow, rollover hoop, seat frame | Fuselage | 40 |  | 40
Tail surfaces, weld and assemble | Tail | 55 |  | 55
Spar: cut, drill, rivet, both panels + center | Wing | 90 |  | 90
Cut and jig 31 fir truss ribs | Wing | 45 |  | 45 | 75 min each
D-tube leading edge | Wing | 45 |  | 45
Wing assembly, TE, tips, dihedral set | Wing | 50 |  | 50
Spoilerons, hinges, springs | Wing | 30 |  | 30 | You have done these
Wing joint fittings and fit-up | Wing | 35 |  | 35 | Machine shop
Sprung main gear, nose gear, steering | Gear | 50 |  | 50
Brake install, rotor adapters, bleed | Gear | 20 |  | 20
Elevator and rudder runs | Controls | 40 |  | 40
Spoileron cables, pulleys, rigging | Controls | 25 |  | 25
Engine mount, install, fuel, exhaust | Power | 55 |  | 55
Cover and finish, 430 sq ft | Finish | 120 |  | 120 | Slowest single task
Final assembly, rigging, weigh, debug | Assembly | 75 |  | 75
Remakes and learning curve | Contingency | 85 |  | 85
RAW TOTAL |  |  |  | 990
Experience factor |  | 70% |  |  | Your estimate of my estimates
ADJUSTED TOTAL HOURS |  |  |  | 693
Hours per week |  | 12
Calendar years |  | 1.1

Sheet: Performance
Performance, driven live off the Weight sheet
INPUTS
Wing span (ft) | 31.00 | 3-piece: 8 ft center, 11.5 ft outer panels
Wing area (sq ft) | 130.00 | Constant chord 50 in
Equiv flat plate area f (sq m) | 0.45 | Back-solved from Sky Pup 12:1, plus trike gear
Oswald efficiency e | 0.85
CLmax, clean | 1.40 | Sky Pup section, no flaps
Engine shaft hp | 28.00 | Hirth F-33
Prop efficiency, cruise | 0.75 | 60 in wood, fixed pitch
Prop efficiency, climb | 0.72
Static thrust (lb) | 211.00 | 28 hp on a 60 in disc, FM 0.75
Roll friction + drag coeff | 0.10 | Grass
Cruise speed (mph) | 50.00
Fuel burn at cruise (gph) | 1.40 | 2-stroke, part throttle
Fuel capacity (gal) | 5.00
Design pilot (lb) | 170.00
Fuel aboard (lb) | 30.00
DERIVED
Gross weight (lb) | 496.0
Gross weight (N) | 2206.31712
Span (m) | 9.45
Wing area (sq m) | 12.08
L/D max | 11.5 | Sky Pup is 12:1
Stall speed (mph) | 32.7 | Part 103 limit 27.6 mph
Liftoff speed (m/s) | 16.79
Takeoff accel (m/s2) | 2.57
GROUND ROLL (ft) | 180.1012613 | Target under 200 ft
Cruise speed (m/s) | 22.35
Parasite power at cruise (W) | 3077.978724
Induced power at cruise (W) | 1491.392643
Shaft hp required at cruise | 8.2
Best climb speed (m/s) | 19.30
Power required at Vy (W) | 3709.38221
RATE OF CLIMB (fpm) | 1010.333265
ENDURANCE (hours) | 3.6
RANGE (statute miles) | 178.5714286 | Less reserve
Wing loading (lb/sq ft) | 3.82
Power loading (lb/hp) | 17.71
Glide distance from 1000 ft AGL (mi) | 2.2
Max achievable g = (Vne/Vstall)^2. Design limit 4.7g, ultimate 7.0g makes the wing stall-limited.

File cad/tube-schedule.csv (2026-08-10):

# | TUBE SIZES ARE PROVISIONAL - no member here has been sized against a load case. Not for fabrication.
id | from | to | stock | OD_in | wall_in | material | cl_length_in | weight_lb | side | min_joint_angle_from_deg | min_joint_angle_to_deg | description
1 | NB_R | AL_R | long | 1.0 | 0.049 | 4130 | 66.34 | 2.748 | R | 29.9 | 92.6 | lower longeron, nose bow to aft frame
2 | NB_L | AL_L | long | 1.0 | 0.049 | 4130 | 66.34 | 2.748 | L | 29.9 | 92.6 | lower longeron, nose bow to aft frame
3 | NT_R | AU_R | long | 1.0 | 0.049 | 4130 | 66.51 | 2.756 | R | 83.2 | 26.3 | upper longeron, nose bow to aft frame
4 | NT_L | AU_L | long | 1.0 | 0.049 | 4130 | 66.51 | 2.756 | L | 83.2 | 26.3 | upper longeron, nose bow to aft frame
5 | NB_R | NT_R | long | 1.0 | 0.049 | 4130 | 20.02 | 0.83 | R | 55.2 | 83.2 | nose bow post
6 | NB_L | NT_L | long | 1.0 | 0.049 | 4130 | 20.02 | 0.83 | L | 55.2 | 83.2 | nose bow post
7 | NB_R | MS_R | diag | 0.75 | 0.035 | 4130 | 38.43 | 0.855 | R | 29.9 | 55.1 | forward side diagonal
8 | NB_L | MS_L | diag | 0.75 | 0.035 | 4130 | 38.43 | 0.855 | L | 29.9 | 55.1 | forward side diagonal
9 | MH_R | AU_R | diag | 0.75 | 0.035 | 4130 | 36.69 | 0.816 | R | 70.9 | 26.3 | aft side diagonal
10 | MH_L | AU_L | diag | 0.75 | 0.035 | 4130 | 36.69 | 0.816 | L | 70.9 | 26.3 | aft side diagonal
11 | MH_R | MS_R | hoop | 1.125 | 0.058 | 4130 | 22.0 | 1.21 | R | 70.9 | 55.1 | main hoop, lower leg
12 | MH_L | MS_L | hoop | 1.125 | 0.058 | 4130 | 22.0 | 1.21 | L | 70.9 | 55.1 | main hoop, lower leg
13 | MS_R | MP_R | hoop | 1.125 | 0.058 | 4130 | 15.07 | 0.829 | R | 84.3 | 95.7 | main hoop, upper leg to the spar pickup
14 | MS_L | MP_L | hoop | 1.125 | 0.058 | 4130 | 15.07 | 0.829 | L | 84.3 | 95.7 | main hoop, upper leg to the spar pickup
15 | RF_R | RP_R | frame | 0.875 | 0.049 | 4130 | 35.0 | 1.26 | R | 180.0 | 89.2 | rear frame post
16 | RF_L | RP_L | frame | 0.875 | 0.049 | 4130 | 35.0 | 1.26 | L | 180.0 | 89.2 | rear frame post
17 | AL_R | AU_R | frame | 0.875 | 0.049 | 4130 | 6.0 | 0.216 | R | 90.0 | 70.9 | aft frame post
18 | AL_L | AU_L | frame | 0.875 | 0.049 | 4130 | 6.0 | 0.216 | L | 90.0 | 70.9 | aft frame post
19 | NT_L | NT_R | frame | 0.875 | 0.049 | 4130 | 16.0 | 0.576 | R | 88.3 | 88.3 | nose bow crown
20 | MP_L | MP_R | spar | 1.25 | 0.058 | 4130 | 16.0 | 0.983 | R | 95.7 | 95.7 | FRONT SPAR carry-through
21 | RP_L | RP_R | spar | 1.25 | 0.058 | 4130 | 16.0 | 0.983 | R | 89.2 | 89.2 | REAR SPAR carry-through
22 | MS_L | MS_R | hoop | 1.125 | 0.058 | 4130 | 19.0 | 1.045 | R | 84.3 | 84.3 | main hoop shoulder cross
23 | AL_L | AL_R | frame | 0.875 | 0.049 | 4130 | 12.0 | 0.432 | R | 90.0 | 90.0 | aft frame lower cross, boom pickup
24 | AU_L | AU_R | frame | 0.875 | 0.049 | 4130 | 12.0 | 0.432 | R | 90.0 | 90.0 | aft frame upper cross, boom pickup
25 | BM_C | TP_C | boom | 3.5 | 0.049 | 4130 | 88.0 | 13.23 | C | 180.0 | 180.0 | tail boom
26 | NGU_C | NAX_C | gear | 1.25 | 0.058 | 4130 | 16.55 | 1.017 | C | 180.0 | 67.8 | nose leg, raked
27 | NGF_C | NAX_C | gear | 1.25 | 0.058 | 4130 | 20.02 | 1.231 | C | 180.0 | 67.8 | nose leg forward drag strut (SEE NGF_C NOTE)
28 | MGF_R | MAX_R | gear | 1.25 | 0.058 | 4130 | 22.06 | 1.356 | R | 180.0 | 39.6 | main trailing arm
29 | MGF_L | MAX_L | gear | 1.25 | 0.058 | 4130 | 22.06 | 1.356 | L | 180.0 | 39.6 | main trailing arm
30 | MAX_R | MGS_R | gear | 1.25 | 0.058 | 4130 | 21.87 | 1.345 | R | 39.6 | 180.0 | main coil-over
31 | MAX_L | MGS_L | gear | 1.25 | 0.058 | 4130 | 21.87 | 1.345 | L | 39.6 | 180.0 | main coil-over
 |  |  |  |  |  | TOTAL | 915.6 | 48.37

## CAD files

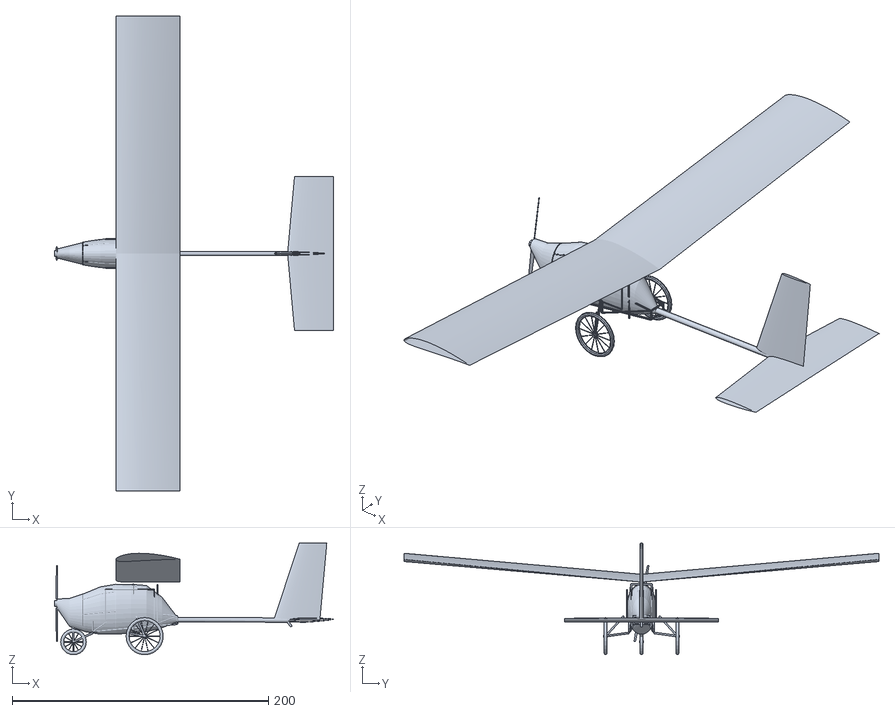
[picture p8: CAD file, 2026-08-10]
model/nuthatch.stl
218.0 x 370.6 x 87.0

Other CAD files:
cad/nuthatch-frame-3d.dxf
cad/nuthatch-views-2d.dxf

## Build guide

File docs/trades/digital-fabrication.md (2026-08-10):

# Digital Fabrication: Where CNC, Laser, and Printing Actually Pay

**Question asked:** where can 3D printing, laser cutting, or CNC improve time,
quality, and efficiency across the whole project?

**Answer:** roughly **90 to 160 adjusted hours**, taking the build from 693 to
somewhere between 537 and 607. The largest single block of it is not a
manufacturing task at all — it is the 85-hour *remakes and learning curve* line,
which is what accuracy upstream buys you.

**The organizing principle, and it decides every case below:**

> **Use digital fabrication for tooling, not for flight parts.**

Tooling has no weight penalty, no airworthiness argument, no fatigue life, and no
UV exposure. A printed jig that is wrong gets reprinted for two dollars. A printed
flight part costs weight forever — [wingtip-caps.md](wingtip-caps.md) already
worked one case and every printed option landed 2 to 3× heavier than the laminate
it replaced. That result generalises.

**And the timing is right.** `open-questions.md` opens with *"Nothing in this
project is drawn yet."* Everything here has to be drawn anyway. **Drawing it so
that it also outputs DXF and STL is nearly free at this stage and expensive to
retrofit.** This is a decision to make before the first drawing, not after.

Status: recommendation. No drawings committed.

---

## 1. Where the hours are, and what can be taken out

Raw hours from the Hours sheet of `analysis/weight-cost-hours.xlsx`, with the
project's own 0.7 experience factor applied at the end.

| Task | Raw hr | Conservative | Optimistic | Intervention |
|---|---|---|---|---|
| Weld jig and fuselage structure | 130 | **−20** | **−35** | CNC ply eggcrate jig; printed tube coping saddles; laser 4130 gussets |
| Nose bow, rollover hoop, seat frame | 40 | −4 | −8 | printed bend formers, laser-cut tabs |
| Tail surfaces, weld and assemble | 55 | −8 | −15 | same coping saddles; laser-cut hinge and horn set |
| Spar: cut, drill, rivet | 90 | −10 | −18 | printed cap-separation spacers, drill templates, CNC web |
| Cut and jig 31 fir truss ribs | 45 | **−12** | **−18** | CNC rib jig board, routed ply gussets |
| D-tube leading edge | 45 | −5 | −10 | CNC-cut ply developments, printed bend forms |
| Wing assembly, TE, tips, dihedral | 50 | −4 | −8 | printed dihedral and incidence setting fixtures |
| Spoilerons, hinges, springs | 30 | −3 | −6 | laser-cut hinge and horn set |
| Wing joint fittings and fit-up | 35 | −6 | −12 | CNC rods and sleeves, printed reaming jigs |
| Main gear, nose gear, steering | 50 | −5 | −10 | printed bend formers, laser-cut mount plates |
| Brakes, rotor adapters, bleed | 20 | −2 | −4 | CNC rotor-to-hub adapters (already planned in §11) |
| Elevator and rudder runs | 40 | −5 | −9 | laser-cut bellcranks, horns, brackets |
| Spoileron cables, pulleys, rigging | 25 | −3 | −5 | laser-cut brackets, printed pulley cages |
| Engine mount, install, fuel, exhaust | 55 | −5 | −10 | printed mock-up engine, laser-cut mount tabs |
| **Cover and finish, 430 ft²** | **120** | **0** | −3 | **almost nothing — see §5** |
| Final assembly, rigging, weigh | 75 | −6 | −12 | better upstream fit-up |
| **Remakes and learning curve** | **85** | **−25** | **−40** | **the big one — accuracy moves into CAD** |
| **TOTAL** | **990** | **−123** | **−223** | |

| | Raw | Adjusted (×0.7) | At 12 hr/week |
|---|---|---|---|
| Baseline | 990 | **693 hr** | 1.11 yr |
| Conservative | 867 | **607 hr** | 0.97 yr |
| Optimistic | 767 | **537 hr** | 0.86 yr |

The 750-hour target was already being met at 693. This is not about hitting the
target — it is about **quality and margin**, and about the fact that a fifth of
the saving comes from simply not making parts twice.

Treat these as estimates of estimates. The Hours sheet already applies a 0.7
factor described as *"your estimate of my estimates,"* and this table sits on top
of that.

## 2. The four that matter most

### A. One laser-cut 4130 sheet package

**The single highest quality-per-dollar move in the project.** Every flat steel
part on the aircraft — cluster gussets, bracket tabs, bellcranks, control horns,
hinge plates, gear mount plates, seat and harness anchor plates, engine mount
tabs, tail attach fittings — is a 2D profile in sheet. Nest them all on one or two
sheets, send one DXF, and every one comes back identical, symmetric, and to
drawing.

This is worth more in **quality** than in hours. Hand-cut and filed steel brackets
are where a one-off airframe accumulates asymmetry, and §9 already flags that
spoileron roll authority is *"adequate rather than crisp"* — an aircraft that is
not symmetric spends control travel it does not have.

**Caveat, and it is not optional.** Laser-cut 4130 has a hardened, brittle heat
affected zone at the edge, typically 0.005–0.015 in deep. Two consequences:

- Dress the edges of any fatigue-loaded part.
- **Do not laser-cut holes to final size.** Laser holes are slightly tapered and
  put HAZ directly in the bearing surface. §13 establishes that **bolt bearing in
  the tube wall governs the entire wing joint design** — undersize every hole on
  the laser and ream to final size afterward.

### B. Printed tube coping saddles

The fuselage is welded 4130 and every tube end has to be fishmouthed to fit the
tube it meets. Hand coping with a hole saw or grinder is slow, and it is where
fit-up error compounds into a fuselage that is out of square.

Model the joint in CAD, generate the intersection, and print a **clamp-on saddle
that wraps the tube and guides the cut**. Cheap, reusable across identical joints,
and it converts a skilled eyeballing task into a tracing task.

This is the biggest single hour saving in the table because it applies to the
130-hour fuselage and the 55-hour tail both.

**Print jigs in PLA, not ASA.** PLA is the most dimensionally stable of the common
filaments (~0.2–0.3% shrink against 0.5–0.8% for ASA and ABS), stiffer, and
cheaper. Jigs live indoors and never see sun or heat, so ASA's advantages are
irrelevant. The ASA guidance in [wingtip-caps.md](wingtip-caps.md) is for parts
that fly.

**But printed jigs cannot go near a weld.** Tack welding radiates enough heat to
soften PLA within an inch or two. Printed saddles are for **cutting and drilling
only** — the weld jig itself needs steel or plywood locators.

### C. CNC-cut plywood jigs: the fuselage eggcrate and the rib board

Two separate jobs, same technology.

**Fuselage jig.** Cut station profiles from plywood on a router, slot them onto a
spine, and the fuselage is located in three dimensions by geometry rather than by
measurement. This is the classic eggcrate jig, it is a natural CNC job, and it
replaces a substantial part of the 130-hour line that is *building the jig* rather
than building the aircraft.

**Rib jig.** §8 specifies 31 Douglas fir truss ribs at 75 minutes each. A CNC-cut
baseboard with a locating pocket for every truss member turns each rib into
drop-in-and-glue. Combined with pre-cut gussets this is realistically 75 minutes
down to 45–50, and — more valuable — **31 ribs that are actually identical**,
which is what a constant-chord wing was chosen for in §6.

**Caveat: do not laser-cut structural plywood.** A laser leaves a charred edge,
and char is a weak boundary layer that adhesive cannot bond through. For the ply
gussets that carry rib shear, **CNC rout them** — or laser them and sand every
glue face back to clean wood, which gives the hours back. Laser is fine for
non-structural templates, patterns, and jig parts.

### D. Printed drill and reaming jigs

The highest-consequence holes on this aircraft are the wing joint bolts. §13 sizes
them on **bolt bearing in the tube wall**, and notes the internal rod's job is
*"preventing the tube from ovalizing at the bolt hole, which is what makes the
published bearing allowable actually apply."* That allowable assumes a clean,
round, correctly located hole.

Printed drill jigs with pressed-in hardened steel bushings are cheap and turn hole
location and squareness from a skill into a fixture. Apply to the spar cap bolt
patterns, the rib-to-spar locations, and every fitting pattern that has to match
across a joint mated every flight.

## 3. The special case: slat geometry

§10 says slats are mandatory and that *"slat gap, chord, overlap, and droop should
be copied dimension-for-dimension from a known installation rather than derived.
Millimetres decide whether a slat works or is pure drag."*

**This is the best use of printing in the project, and it is not a part — it is a
process.** Print bracket sets that hold the slat at a known gap, overlap, and
droop. Change one dimension, print another set, compare. It converts a parameter
nobody wants to derive into something that can be measured on the aircraft.

**Print to find the geometry. Machine or weld it to fly it.** Slats carry
substantial load at high alpha, and the loss of one on a two-axis aircraft is a
roll upset against roll authority §9 already calls adequate rather than crisp. The
printed brackets should end their life as **weld fixtures** that hold the slat in
position while the real 4130 brackets are tacked.

Same pattern applies to the cockpit geometry open question — print or CNC a
full-size seating mock-up rather than deriving stick, pedal, and throttle
positions on paper.

## 4. Straightforward printed flight parts

Small, non-structural, and genuinely fine to print in ASA:

- Junco tablet mount and instrument pod
- Cable fairleads, pulley cages, cable exit fairings
- Inspection covers and access hatches
- Vent scoops, tank fittings, fuel line clamps
- Wire looms and standoffs
- Control stick grip
- Placards
- Wingtip caps — worked separately in [wingtip-caps.md](wingtip-caps.md)

The rule that keeps this safe: **nothing in a primary load path, and nothing whose
failure removes a control.** A printed fairlead that cracks is a nuisance. A
printed pulley bracket that lets a spoileron cable jump its sheave is not, so that
one is laser-cut steel.

## 5. Where it does not help, and this is worth saying

**Covering is 120 hours — the single largest task — and digital fabrication does
essentially nothing for it.** Printed rib-stitch spacing guides are worth a couple
of hours and that is all.

The lever on covering is **material choice, not fabrication method.** §14 already
prices it: Oratex buys about 75 hours for roughly $1,400 against Stewart. That one
decision is worth more time than every intervention in §2 combined, and it is
already sitting in the design log unresolved.

If hours genuinely bind harder than dollars, **settle the covering system before
buying a CNC router.**

## 6. Given the shop that actually exists

The shop is **five 3D printers, a desktop laser cutter, a desktop CNC, and a
Maslow 4 × 8 CNC router.** That removes the tooling-acquisition question entirely
and changes three of the conclusions above.

### The Maslow is the one that changes the workflow, not just a task

A 4 × 8 work area is larger than every part on this aircraft except the spar. That
makes a **full-size digital loft** possible: draw once in CAD, then cut every
template, jig, form, and former at full scale from sheet goods. That replaces the
traditional mylar-lofting workflow rather than accelerating it, and it is the
single biggest capability in the list.

What it should cut:

- **Fuselage side-truss layout boards.** The fuselage is about 190 in, so two
  spliced sheets. Pocket or engrave the truss geometry full size, pin the tubes to
  it, and tack. This is how tube fuselages get built accurately, and it is the
  method the 130-hour line assumes you improvise.
- **The fuselage eggcrate station jig.** Two to three sheets.
- **The rib jig board.** Entire jig on one sheet.
- **D-tube bending forms**, and the developed 1/16 birch ply shapes themselves.
- **Gear leg bend formers**, wing assembly cradles, tail rib templates.

**Verify the calibration before trusting it.** A Maslow is a belt-and-sled machine
with accuracy in the region of 1/32 in over a sheet, which is fine for jigs and
templates and not fine for fittings. Cut a large test rectangle and measure the
diagonals before cutting the rib jig, because that jig defines the airfoil on all
31 ribs. At a 50 in chord, ±1 mm is 0.08% of chord and acceptable — but only if it
is ±1 mm and not ±4.

**Thin ply needs hold-down.** 1/16 in birch on a router wants a sacrificial board,
a downcut bit, and either vacuum or tape-and-CA, plus tabs. Otherwise it lifts.

### The desktop laser cannot do the part that matters most

A desktop laser does thin plywood, templates, patterns, and marking. **It does not
cut 4130 sheet.** The single highest-value intervention in §2A therefore stays an
outside order — a laser, plasma, or waterjet service — and it is the only thing on
this list that has to leave the shop.

Everything in §2C's caveat still applies to the laser: it chars plywood, and char
is a weak adhesive boundary. **Rout the structural rib gussets on the desktop CNC;
use the laser for non-structural templates and patterns.**

### Five printers changes throughput, which changes what is worth printing

The 12–20 mould sections in [wingtip-caps.md](wingtip-caps.md), and the hundred-odd
tube coping saddles in §2B, stop being a month of printing and become a few
overnight runs. Two consequences:

- **Coping saddles become obviously worth it.** At one printer the print time
  competes with just coping the tubes by hand. At five it does not.
- **The tip cap decision gets cheaper on both branches.** Print the ASA tips for
  Phase I *and* print the female mould, because neither is now a scheduling
  problem. The measure-then-decide sequence stands, but nothing is gated on print
  time.

### The desktop CNC covers the fittings, with one substitution

It should do the **rotor-to-hub adapters** (§11, currently "machine yourself"),
bracket blanks, spacers, and drill-jig bushing plates.

**What is missing is a lathe**, for §13's internal joint rods and external sleeves.
Do not buy one for this. §13 only requires close tolerance *"in the last two inches
near each bolt"* — so **buy precision-ground rod and honed tube stock**, which
arrives round and on-size, and machine nothing but the chamfer and the holes. That
removes the lathe from the critical path entirely.

**Also missing: a vacuum pump.** The carbon tip cap weight case in
[wingtip-caps.md](wingtip-caps.md) depends on bagging — 0.54 lb per tip bagged
against 1.13 lb wet-laid. A pump is $150–300 and it is the difference between the
cap being weight-neutral and being a penalty.

## 7. Cost, revised

| | |
|---|---|
| Laser-cut 4130 sheet package (**the only outside order**) | $300–600 |
| Sheet goods for jigs — MDF and ply, 5–8 sheets | $120–250 |
| Filament, tooling only | $80–200 |
| Vacuum pump and bagging consumables | $150–300 |
| Precision-ground rod and honed tube stock (replaces lathe work) | in BOM |
| Machined rotor adapters, bracket blanks | in BOM, now in-house |
| **Net add** | **$650–1,350** |

The BOM carries a 30% contingency line, roughly $3,300. This fits inside it, and
some of it returns as material not wasted on remakes.

The $150–400 CNC jig line from the first version of this estimate is now sheet
goods only. The machines are already paid for, which means **the optimistic column
in §1 is the more realistic one** — most of the gap between conservative and
optimistic was tooling access and print throughput, and neither is a constraint
here.

## 8. The strategic argument, for an open-hardware aircraft

The README licenses this under CERN-OHL-S and says the two files worth reading
first are the design log and the measured weights, because *"drawings exist for a
dozen aircraft in this class. Reasoning does not."*

**The same gap exists in fabrication data. Nobody in this class ships DXF and STL.**

If the CAD is built to output cut files, then publishing them costs nothing and
gives a builder something no other Part 103 design offers: send one file to a
laser service and every bracket on the aircraft arrives correct. That directly
addresses the open question about *"drafting for yourself or for publication"* —
cut files are worth more to a second builder than full-size rib templates, and
they are a by-product of drawing it this way rather than extra work.

It also makes the *"you are the manufacturer"* disclaimer more honest, not less:
a builder reproducing geometry from a file is far less likely to introduce the
silent asymmetries that hand fabrication produces.

## 9. What this does not settle

- Every hour figure here is an estimate applied on top of estimates that already
  carry a 0.7 correction factor. Treat the *ranking* as more reliable than the
  totals.
- Maslow calibration. The rib jig defines the airfoil on all 31 ribs, so the
  machine's real accuracy over a full sheet needs measuring before it cuts that
  board — not assuming from the specification.
- CAD hours. This assumes the aircraft gets drawn in 3D, which is not obviously
  the plan — the Hours sheet excludes design time entirely, and the clean-sheet
  estimate in §4 of the design log put design work at about 300 hours.
- Which parts are structural enough to need HAZ removal after laser cutting.
  That is a per-fitting call and belongs on the drawings.
- Whether laser-cut covering fabric is viable. Polyester edges seal under a laser,
  which is interesting, but there is no precedent in aircraft covering and this is
  not the project to establish one.

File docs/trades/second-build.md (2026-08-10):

# How Long Does the Second One Take?

**Question asked:** with all the same templates, jigs, and tooling already built,
how many hours is aircraft number two?

**Answer: 370 to 460 adjusted hours, against 575 for the first one** — somewhere
between half and two-thirds. Call it **7 to 9 months at 12 hours a week**, against
about 11 months for the first.

The single largest line item that disappears is not a manufacturing task. It is
the 85-hour *remakes and learning curve* budget, which drops by roughly 85%.

Status: estimate. Everything here sits on top of the Hours sheet in
`analysis/weight-cost-hours.xlsx`, which already carries its own 0.7 correction.

---

## 1. Line by line

Build 1 column is the raw estimate less the digital-fabrication savings from
[digital-fabrication.md](digital-fabrication.md). Retention is the fraction of
that work which survives into a second aircraft with the tooling already in hand.

| Task | Raw | Build 1 | Retention | Build 2 |
|---|---|---|---|---|
| Weld jig and fuselage structure | 130 | 103 | 0.60 | 62 |
| Nose bow, rollover hoop, seat frame | 40 | 34 | 0.70 | 24 |
| Tail surfaces, weld and assemble | 55 | 44 | 0.70 | 31 |
| Spar: cut, drill, rivet | 90 | 76 | 0.70 | 53 |
| Cut and jig 31 fir truss ribs | 45 | 30 | 0.75 | 22 |
| D-tube leading edge | 45 | 38 | 0.70 | 27 |
| Wing assembly, TE, tips, dihedral | 50 | 44 | 0.65 | 29 |
| Spoilerons, hinges, springs | 30 | 26 | 0.70 | 18 |
| Wing joint fittings and fit-up | 35 | 26 | 0.60 | 16 |
| Main gear, nose gear, steering | 50 | 43 | 0.70 | 30 |
| Brakes, rotor adapters, bleed | 20 | 17 | 0.65 | 11 |
| Elevator and rudder runs | 40 | 33 | 0.70 | 23 |
| Spoileron cables, pulleys, rigging | 25 | 21 | 0.65 | 14 |
| Engine mount, install, fuel, exhaust | 55 | 48 | 0.60 | 29 |
| **Cover and finish, 430 ft²** | 120 | 119 | **0.85** | **101** |
| Final assembly, rigging, weigh, debug | 75 | 66 | 0.50 | 33 |
| **Remakes and learning curve** | 85 | 53 | **0.15** | **8** |
| **RAW TOTAL** | **990** | **821** | | **530** |

| | Adjusted (×0.7) | At 12 hr/week |
|---|---|---|
| Original estimate, no tooling | 693 hr | 1.11 yr |
| **Build 1**, with digital tooling | **575 hr** | 0.92 yr |
| **Build 2**, same tooling and templates | **371 hr** | **0.59 yr (7 months)** |

## 2. Sanity check, and an honest range

That bottom-up result implies a **65% learning curve** for unit two. Aerospace
manufacturing normally uses 80–85%.

Landing steeper than the industry norm is defensible here, because the standard
curve assumes you are *also* building tooling and refining process as you go —
both of which are already paid for. But 65% is on the optimistic side of
defensible, so the honest answer is a range rather than a number:

| Method | Build 2 |
|---|---|
| Bottom-up, per task (above) | **371 hr** |
| Textbook 80% curve on 575 | **460 hr** |
| Textbook 85% curve on 575 | 489 hr |

**Use 370–460 hours.** Anything under 350 is wishful; anything over 500 means the
tooling was not actually reused.

If it ever went further, on the same bottom-up curve: unit 3 about 287 hr, unit 4
about 239, unit 5 about 208 — with the covering line increasingly dominating,
because it barely improves.

## 3. Why covering becomes the whole problem

At **101 of the 371 hours — 27% of the second aircraft — covering is by far the
largest single task**, and it is the one thing on the list that digital
fabrication, jigs, and experience all fail to touch. It is 430 ft² of hand work
and it takes what it takes.

This changes the weight of the §14 decision considerably. Oratex buys roughly 75
hours over Stewart for about $1,400, and on a second build that is **20% of the
entire aircraft**. §14 currently leans Stewart on weight grounds. **If a second
aircraft is genuinely on the table, that conclusion should be revisited**, because
the hours case for Oratex roughly doubles when the covering is 27% of the build
rather than 17%.

## 4. What is not in either number

**Design and CAD.** The Hours sheet excludes design time entirely, and the
clean-sheet estimate in §4 of the design log put it at roughly 300 hours. Build 1
pays that plus the time to build every jig, fixture, and printed saddle. **Build 2
pays none of it.** So the real gap between the two aircraft is wider than the
table shows — the table is comparing only the parts that were ever counted.

**Tooling wear.** Printed PLA jigs, plywood fixtures, and CNC-cut boards will not
be pristine after one aircraft. Budget a few hours to reprint saddles and re-cut
anything that has been drilled through, and store the CAD and cut files somewhere
they will still open in five years. That last one is not a joke — the tooling that
matters most on build 2 is the file, not the jig.

## 5. Cost, which changes less than hours

Materials do not learn. Most of the BOM repeats in full. What does not:

| | |
|---|---|
| Tooling line, jig sheet goods, filament, vacuum pump | **does not repeat** (~$550–950) |
| Laser-cut 4130 sheet package | repeats — but nesting and setup are already paid |
| DAR inspection and N-number, $755 | repeats for EAB, **$0 for Part 103** |
| Everything else | repeats in full |

**One actionable thing: order two sets of laser-cut 4130 on the first order.** The
DXF is done either way, and the marginal cost of a second nested set is far below
the first. The same logic applies to spar cap stock and any minimum-order material.
If a second aircraft is even plausible, decide it before that first order goes out.

## 6. The regulatory difference is larger than the hours difference

**Part 103 has no airworthiness certificate, no inspection, no N-number, and no
builder rule.** A second Part 103 aircraft is regulatorily free.

**EAB is not.** Each aircraft needs its own airworthiness certificate and DAR
inspection, and the amateur-built major portion rule applies to each one
separately. Two aircraft built for your own education and recreation is ordinary;
a pattern of building and selling starts to look like manufacturing, and the
repairman certificate that lets the builder sign condition inspections is issued
per aircraft to one builder and does not transfer with a sale.

**None of that is a ruling and it should not be treated as one.** If a second EAB
aircraft is a real plan rather than a thought experiment, ask a DAR before the
first one is finished, not after — it is a cheap conversation and the answer may
change what gets documented during build 1.

## 7. What this does not settle

- Retention factors are judgement, not data. The `build-log/` directory exists to
  replace them with measurements — **log actual hours per task on build 1** and
  this estimate becomes arithmetic instead of a guess.
- Whether the same engine, covering system, and configuration are used twice. Any
  change resets part of the learning curve for that subsystem.
- Whether build 2 is the same configuration at all. An EAB first aircraft and a
  Part 103 second one share drawings but not weights, and the strip-down work in
  the `103 Strip` column is not costed here.

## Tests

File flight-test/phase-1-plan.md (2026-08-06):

# Phase I Flight Test Plan

*(skeleton, to be completed before the airworthiness inspection)*

## Before first flight

- Weight and balance from actual scale readings, all three points
- CG verified at 30% MAC across the full pilot weight range
- Full-deflection control checks, both directions, eyes on the surfaces
- Spoileron aerodynamic close direction measured at 25 and 35 mph on taxi
- Wing pin engagement verified, all four per side, lanyards visible
- Static thrust measured
- Engine run to temperature, both ignition circuits checked independently
- Junco logging confirmed to SD

## Test area

To be assigned in the operating limitations. Requirements: long paved runway,
minimal traffic, no jet mix, and 40 hours of flyable airspace.

## Test sequence

1. High-speed taxi, nosewheel steering and brake authority
2. Runway hops, elevator authority in ground effect
3. First flight: pattern altitude, straight and level, trim, gentle turns
4. Stall series, progressive, at altitude, clean then with slats characterized
5. Spoileron roll rate and authority, measured against stick position via Junco
6. Climb performance, corrected for density altitude
7. Glide ratio, measured by timed descent
8. Takeoff and landing distances, measured
9. Envelope expansion to Vne in increments

## Data to publish

Every number in the README that is currently an estimate, replaced with a
measurement, with the Junco logs alongside it.

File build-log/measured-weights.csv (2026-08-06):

group | item | estimate_lb | measured_lb | station_in | notes
Wing | Spar: 1.25 sch40 6061 caps, wrapped 0.020 web, foam core | 22.0 |  | 74
Wing | Ribs, 31 ea, Douglas fir truss with ply gussets | 8.0 |  | 76
Wing | D-tube leading edge, 1/16 birch ply | 12.0 |  | 62
Wing | Rear spar / spoileron hinge spar | 5.0 |  | 86
Wing | Trailing edge stock | 3.0 |  | 100
Wing | Spoilerons, 2, hinges and return springs | 4.0 |  | 82
Wing | Leading edge slats, full span | 6.0 |  | 58
Wing | Wing joints: solid rods, sleeves, 8 AN bolts | 7.0 |  | 70
Wing | Fabric and finish, wing, 260 sq ft | 14.0 |  | 76
Wing | Wing misc hardware | 4.0 |  | 74
Fuselage | 4130 longerons, uprights, diagonals, gussets | 31.0 |  | 80
Fuselage | Nose bow, structural, ahead of pedals | 5.0 |  | 44
Fuselage | Rollover hoop | 4.0 |  | 58
Fuselage | Cabane / wing carry-through | 6.0 |  | 68
Fuselage | Seat frame, pan, Confor foam | 5.0 |  | 58
Fuselage | 5-point harness | 3.0 |  | 58
Fuselage | Turtledeck formers and stringers | 3.0 |  | 110
Fuselage | Fabric and finish, fuselage, 100 sq ft | 5.5 |  | 80
Fuselage | Windshield | 4.0 |  | 40 | deleted on 103 build
Tail | Horizontal stab and elevator, 30 sq ft | 12.0 |  | 182
Tail | Vertical fin and rudder, 15 sq ft | 6.0 |  | 178
Tail | Tail attach fittings and bracing | 2.0 |  | 180
Gear | Main gear, sprung 4130 tubes | 8.0 |  | 78
Gear | Main wheels and tires, 5.00-5 | 12.0 |  | 78
Gear | Bicycle hydraulic disc brakes, rotors, adapters | 2.0 |  | 78
Gear | Nose gear leg, wheel, steering linkage | 12.0 |  | 34
Gear | Gear mounts and fittings | 4.0 |  | 70
Controls | Stick, elevator run, bellcranks | 7.0 |  | 60
Controls | Rudder pedals and cables | 5.0 |  | 50
Controls | Spoileron line, pulleys, springs | 4.0 |  | 72
Power | Hirth F-33, 28 hp, dry with exhaust | 35.0 |  | 14
Power | Belt reduction drive | 10.0 |  | 20
Power | Propeller, wood, 60 in | 8.0 |  | 2
Power | Engine mount | 5.0 |  | 13
Power | Fuel tank 5 gal, lines, shutoff, primer | 8.0 |  | 48
Systems | Junco, tablet, mount | 4.0 |  | 42 | deleted on 103 build
Systems | Wiring, switches, master | 3.0 |  | 50
Systems | BRS hard points and bridle channel | 3.0 |  | 70
Systems | AN hardware, paint, placards | 8.0 |  | 75

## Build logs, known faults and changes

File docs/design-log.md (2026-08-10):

# Design Log

Decisions in the order they were made, with the number that decided each one and
the alternatives that lost. Read this before the drawings.

The current state of it all is on one page in [specs.md](specs.md); what still
blocks drawing is in [open-questions.md](open-questions.md).

---

## Contents

- [0. How the mission got defined](#0-how-the-mission-got-defined)
- [1. Configuration: why not a gyroplane](#1-configuration-why-not-a-gyroplane)
- [2. Configuration: why not a multirotor](#2-configuration-why-not-a-multirotor)
- [3. Powerplant: why not electric](#3-powerplant-why-not-electric)
- [4. Airframe: why derive from an existing design](#4-airframe-why-derive-from-an-existing-design)
- [5. Fuselage: welded 4130, not a wood box](#5-fuselage-welded-4130-not-a-wood-box)
- [6. Wing: constant chord, cantilever, 130 ft²](#6-wing-constant-chord-cantilever-130-ft)
- [7. Spar: aluminum caps and a shear web](#7-spar-aluminum-caps-and-a-shear-web)
- [8. Ribs: Douglas fir truss, not foam](#8-ribs-douglas-fir-truss-not-foam)
- [9. Roll control: spoilerons, not ailerons](#9-roll-control-spoilerons-not-ailerons)
- [10. Slats: mandatory, not optional](#10-slats-mandatory-not-optional)
- [11. Brakes: bicycle hydraulic discs](#11-brakes-bicycle-hydraulic-discs)
- [12. Structural design point: 4.7g limit](#12-structural-design-point-47g-limit)
- [13. Wing joints: bearing, not shear](#13-wing-joints-bearing-not-shear)
- [14. Covering: Stewart waterborne](#14-covering-stewart-waterborne)
- [15. Engine: Hirth F-33](#15-engine-hirth-f-33)
- [16. Propeller: 60 in, two blades, wood](#16-propeller-60-in-two-blades-wood)
- [17. Transport: removable wings, not folding](#17-transport-removable-wings-not-folding)
- [18. Tractor, not pusher — and why that answer is different for electric](#18-tractor-not-pusher--and-why-that-answer-is-different-for-electric)
- [Configurations that lost, with the number](#configurations-that-lost-with-the-number)
- [19. Fabrication method: digital tooling, not digital parts](#19-fabrication-method-digital-tooling-not-digital-parts)
- [20. The common airframe: one structure, both configurations](#20-the-common-airframe-one-structure-both-configurations)
- [21. Owner decisions, 2026-08-09](#21-owner-decisions-2026-08-09)
- [22. Borrowed optimizations: what the ultralight world still has to offer](#22-borrowed-optimizations-what-the-ultralight-world-still-has-to-offer)
- [23. Fly-by-wire and servo-augmented controls: no, except on one surface](#23-fly-by-wire-and-servo-augmented-controls-no-except-on-one-surface)
- [24. Rev F: the cage, the all-steel airframe, and the frame that does three jobs](#24-rev-f-the-cage-the-all-steel-airframe-and-the-frame-that-does-three-jobs)
- [25. Rev G: reclined pilot, enclosed cabin, and the wing brought down onto it](#25-rev-g-reclined-pilot-enclosed-cabin-and-the-wing-brought-down-onto-it)
- [26. Rev H: the whole front is windshield, and the first number for visibility](#26-rev-h-the-whole-front-is-windshield-and-the-first-number-for-visibility)
- [27. The frame becomes data, and the data fails its first check](#27-the-frame-becomes-data-and-the-data-fails-its-first-check)

---

## 0. How the mission got defined

Started as an all-electric autonomous gyroplane with a prerotator for near-vertical
takeoff. Ended as a two-axis wood-and-steel ultralight. Every step of that
narrowing was driven by a number, and the numbers are below.

**Final mission:** single seat, safe, cheap, trailerable, operable from a
300 × 1000 ft backyard with trees at one end, 200 ft takeoff roll or less, 22 ft
garage storage, 16 ft trailer.

---

## 1. Configuration: why not a gyroplane

Gyroplanes cannot use flaps, glide at L/D 4–5, and need a collective-pitch rotor
head to achieve a short takeoff. Energy per hour of flight is roughly twice a
fixed wing's and per mile is nearly three times.

The collective head is also the highest-risk subsystem available: no commercial
source, blade grips carrying ~10,000 lb of centrifugal force in pitch bearings,
and a failure mode that turns the rotor into a rock. **Rejected on efficiency and
on the fact that a fixed-pitch gyro rotor has almost nothing that can fail, and
adding collective throws that away.**

## 2. Configuration: why not a multirotor

Disc loading governs everything. A single-seat multirotor with stacked props runs
about 13 lb/ft²; a 31 ft wing runs 3.8. Induced power goes as the square root of
disc loading, so the multirotor pays roughly three times more per pound just to
stay up, continuously, with no other lift source.

It also has no energy-out mode. Power loss means falling, and the parachute needs
altitude you do not have in the regime the aircraft exists for. **Rejected.**

Reference point: the Jetson ONE uses 13.5 kWh for about 20 minutes.

## 3. Powerplant: why not electric

Battery capital cost is roughly $500/kWh. Gasoline stored in a tank is about
$3/kWh-equivalent. That is a 150x gap in energy storage cost and no parts list
inverts it.

At 2.5 kWh a pure-electric version of this airframe flies 32 minutes for
$17,500. The same airframe on 5 gallons flies 3.6 hours for less.

**Electric was pursued on the hypothesis that it would be cheaper. It is not.**
The airframe retains an electric conversion path, and at 12:1 glide it needs only
about 7 hp to cruise, which makes it a better electric candidate than most. But
not for version one.

Verified along the way: FAA Chief Counsel (2012) holds that batteries count
toward the 254 lb Part 103 empty weight, and that Part 103 imposes no
reciprocating-engine restriction, unlike light-sport. A hybrid Part 103 is legal.
It just is not cheaper.

**Powerplant priority is gasoline first, hybrid second, electric third.** That
ordering is the project's, not a conclusion of this analysis, and the sections
below are written to serve it.

**Electric, if it happens, is EAB only.** Worked in
[trades/pusher-vs-tractor.md §3](trades/pusher-vs-tractor.md): the Part 103
airframe less propulsion is 206 lb, a 15 kW direct-drive electric group adds
about 40 lb, and that is 246 lb before a single cell. Eight pounds of pack
against the 254 lb cap is 0.6 kWh, or **four minutes**. Part 103 electric is not
a weight-optimisation problem, it is arithmetic. **Part 103 stays gasoline.**

That is a limit of the *rule*, not of the airframe. The same analysis found that
on an equal 5 kWh pack Nuthatch would fly roughly **50% longer than the European
electric ULMs it gets compared to** — about 30 minutes against 20 at 50 mph —
because those aircraft fly under a 330 kg gross limit with no empty weight cap at
all, and glide at about 8 where this one glides at 10.7. Every point of L/D is
endurance that does not have to be bought in cells.

**The $500/kWh figure above has not been re-verified** and it is the number the
whole electric argument turns on. Re-check it against current DIY 21700 pack
costs before citing this section again.

## 4. Airframe: why derive from an existing design

A clean-sheet version of this aircraft came out at roughly 2,000 hours and
$21,000, of which about 300 hours was design work and n=1 at first flight.

The Sky Pup is a 1982 design by a trained aeronautical engineer: 31 ft cantilever
wing, 130 ft², 12:1 glide, stall and spin proof, wood and foam and fabric,
450–600 hour build, roughly 350 built and flown with no reported aerodynamic or
structural problems.

**Deriving from it eliminates the design work and replaces n=1 with n=350.** The
delta for the entire safety package is about 100 hours and $1,900.

## 5. Fuselage: welded 4130, not a wood box

Borrowed from the Ison Airbike, which mates a welded steel tube fuselage to an
all-wood wing and has been in production since 1995 at 251 lb empty.

Weight comes out about even with a wood box. Steel wins on the things being
added: nose bow, rollover hoop, harness anchors, gear mounts, engine mount. Those
all want welded joints rather than wood with gussets.

**Addendum (rev E):** the steel argument only ever applied to the
concentrated-load hardware, all of which lives forward of sta 96. The welded
truss now ends there — a **cockpit cage** — and the tail rides a single
straight boom (Kolb architecture, ~80 fishmouth joints and the aft jig
deleted). The cockpit fairing is non-structural: stringers and fabric over
the cage, shaped freely. Worked in
[trades/fuselage-architecture.md](trades/fuselage-architecture.md).

**Addendum 2 (rev F) — the boom goes back to steel.** Rev E chose 6061-T6 on
weight; re-run over the tube sizes actually stocked, the penalty for
**4130 3.50 × .049** is only **+4.4 lb raw and +2.2 lb net** once the welded
boom-root and tail-post clusters replace a machined sleeve joint and its
bolted brackets. The reason the gap is small: a thin-wall boom is
**buckling-limited, not strength-limited**, and steel's 2.9× stiffness very
nearly cancels its 2.89× density — steel never gets to use its 95 ksi. Two
things then decide it: the aluminium-to-steel transition joint disappears
(one material, one process, and the "copy Kolb's fittings" gate retires),
and **4130 has a true endurance limit where 6061-T6 has none** — an aluminium
boom is a fatigue-managed part behind a vibrating two-stroke, a steel one is
not. **Adopted: all-steel cage + boom, fabric over everything.** Worked in
[trades/cockpit-cage.md](trades/cockpit-cage.md).

## 6. Wing: constant chord, cantilever, 130 ft²

**Constant chord** because 31 identical ribs need one template and one jig.
Tapering costs about 40 hours and saves roughly 3% in induced drag.

**Cantilever, not strut-braced.** Struts drop L/D from 12 to about 10, which is a
20% power penalty. Cantilever costs about 9 lb of cap. Cantilever wins by 8x.

**130 ft², not 150.** The larger wing is better for stall speed and takeoff, but
you cannot shrink a wing later and the 20 ft² is the difference between a Part 103
configuration being reachable and not. Cost is 24 ft of takeoff roll.

**No winglets, and shape the tips instead.** Worked in
[trades/winglets.md](trades/winglets.md). A buildable winglet returns +3 to +4.5%
L/D, which is real — but the wing is already three-piece removable, so the garage
and trailer bound the *panel*, not the span. One foot of span beats a 1.0 ft
winglet and adds 4 ft² of wing on the way past. Winglets exist to buy span
efficiency when you cannot buy span, and here you can.

More to the point, **a properly shaped tip is worth +2.9% off the assumed baseline
and +9.5% against a square-cut tip, for zero weight and zero structure.** The
`e = 0.85` every number in this project rests on is a placeholder with a ±0.05
band, which is wider than the winglet's whole benefit. Fitting winglets before the
Phase I glide measurement is tuning below the noise floor of the model.

Tip mass is also the worst mass on this aircraft. A winglet is a mass *and* a
lifting surface at the tip of an 11.5 ft removable panel that carries the
spoilerons, and it feeds torsion into a joint §13 sized for bending. §12's
stall-limited argument is about load factor and says nothing about flutter —
**for which no analysis exists at any configuration.**

One argument does survive: winglets add effective span without adding *area*, so
unlike a span extension they do not move the Part 103 empty weight. If the 103
configuration ever needs span efficiency it cannot pay for in wing area, this is
where to come back.

Carbon, if they are ever built, is fine here — near-zero CTE against fir's 4 is a
far better thermal match than the aluminium-to-birch bond rejected below, and §7's
"undetectable void" objection does not carry to a secondary surface.

**Moulded carbon tip caps instead, and this one is worth building.** Detailed in
[trades/wingtip-caps.md](trades/wingtip-caps.md). Two plies of 3.7 oz cloth
vacuum bagged comes to 0.54 lb per tip against 0.65 lb for a laminated wood bow
with fabric — **weight neutral**, so none of the tip-mass objection above applies.

The reason is not surface finish. **A Hoerner tip's defining feature is a sharp
lower outboard corner, and fabric over a wood bow cannot hold a sharp edge** — it
shrinks into a radius. A moulded part holds it exactly, so the mould enables a
geometry that is otherwise unbuildable on this wing. Symmetry is the second
reason and it is a handling item: two parts off mirrored moulds are identical by
construction, and with §9's roll authority already "adequate rather than crisp,"
a tip mismatch spends spoileron travel holding a wing up.

Two build notes that belong on the drawing rather than in a note. **Print the
mould female and lay up inside it** — wrapping carbon around a printed plug puts
the tool surface on the inside of the part, and the air only touches the outside.
And **isolate the carbon from the aluminium spar caps with a glass ply and
sealant**: carbon is strongly cathodic to aluminium, the caps run to the tip, and
the resulting corrosion happens inside a closed bay where nothing will be seen
until an inspection that may never happen.

Resin fraction is the whole weight budget — bagged runs 55% fibre, wet hand layup
40%. If it is not going to be bagged, use the light cloth anyway. Heavy twill wet
is +1.9 lb over both tips for nothing.

**Printed ASA tips are a Phase I development step, not the final part.** ASA is
2.0 GPa against 45 for a carbon laminate, and since panel stiffness goes as `E·t³`
it takes 1.4 mm of ASA to match a 0.5 mm carbon skin. With internal ribs at
1.2–1.6 mm that lands at **3 to 4 lb across both tips** — 60–75% of the winglet
mass penalty this section just rejected, arriving through the back door on a part
that was supposed to be free. Better than a winglet, because the mass wraps onto
the tip rather than cantilevering outboard and adds no lifting surface, but not
free.

Print them anyway for Phase I: they cost nothing, item 7 of the flight test plan
already measures glide by timed descent, and that measurement is what says whether
the shape earned its keep. If it did, the printed tip becomes the plug for the
female tool and 2 lb comes back off the tips. If glide did not move, the answer
was a plain wood bow all along.

Two print notes. **0.12 mm layers put the ridge height at 0.06 mm, just under the
0.065 mm admissible roughness at 50 mph**, so a fine-layer print needs no filling
at all — coarser layers do. And do not print or paint them black: black ASA in
direct sun reaches 70–80 °C against a Tg near 100 °C.

**Fibre-filled ASA does not change the answer.** CF-ASA raises modulus 2.0 → 5.5
GPa, which on paper allows a 1.01 mm wall instead of 1.41. But chopped fibre needs
a 0.5–0.6 mm nozzle, and two perimeters at 0.6 is 1.2 mm — the thin wall is
unreachable, and at identical geometry the denser filament comes out *heavier*
(3.13 lb against 3.01). The stiffness cashes out in **rib spacing** instead, about
28% wider bays at the same wall. Meanwhile elongation drops from 10–20% to 1–3%,
which is the wrong trade at the one location on the aircraft chosen partly for
impact resistance. Every printed option lands between 2.6 and 3.5 lb; only a
carbon/epoxy laminate reaches weight-neutral.

Use a filled filament if warping across the printed sections is the practical
blocker — that alone justifies it. Prefer **glass** over carbon if so: less
stiffness, but it keeps 3–6% elongation, needs no hardened nozzle, and comes in
light colours, which settles the solar heating note above for free.

## 7. Spar: aluminum caps and a shear web

Bending is carried at maximum distance from the neutral axis. A wrapped tube puts
most of its fiber near the middle, where it weighs full price and does nothing.

At 128,900 in-lb ultimate root moment and 6.3 in of cap separation:

| | Weight |
|---|---|
| Single aluminum tube, 3.5 × 0.156 | 44 lb |
| Aluminum tube caps + foam/sheet web | 22 lb |
| Carbon caps + foam web | 10 lb |

**Aluminum caps chosen.** Carbon is lighter, but the spar is the one part where a
wet-layup void is both unsurvivable and undetectable. Extruded 6061-T6 arrives
with published allowables and stays inspectable. The 12 lb is about 3% of power.

Caps are 1.25 sch 40 6061-T6. Note that hardware-store aluminum pipe is often
6063-T5, which yields around 25 ksi against 40 for 6061-T6. Buy from a metal
supplier.

Architecture is carried over from a Red Bull Flugtag glider the author built and
flew: tube caps top and bottom, foam spacer, aluminum sheet wrapped from one face
down and under and riveted to the top so it forms a double-thickness web. Changes
from that build: one pipe size up, structural epoxy instead of polyurethane glue,
and hemmed web edges instead of tape.

**Strut position matters more than anything else in spar sizing.** Moving the
attach point from 8 ft to 10 ft dropped ultimate bending at the strut station
from 87,400 to 48,700 in-lb, before the design went cantilever.

## 8. Ribs: Douglas fir truss, not foam

Counterintuitive result, at a 50 in chord:

- Foam rib: 0.22 lb of 1 in core + 0.19 lb of cap strips = **0.41 lb**
- Truss rib: 0.09 caps + 0.06 web members + 0.03 gussets = **0.20 lb**

A solid slab of foam outweighs an open truss even at 1.5 lb/ft³. Thirty-one ribs,
so about 6.5 lb saved, and the truss is stronger per pound because diagonals
carry shear where foam just sits there. Costs about 29 hours.

**Douglas fir, lumber yard, select vertical grain.** Roughly $1/board-foot against
$15–25 for aircraft spruce. Fir is 30% denser than spruce so ribs come to 8 lb
rather than 6.2, and $800 stays in your pocket. You are grading the wood yourself:
vertical grain, six or more rings per inch, no knots or runout, reject grain
deviation worse than 1 in 15.

Wood ribs also permit proper rib stitching and remove the solvent constraint that
foam ribs impose on the covering system.

## 9. Roll control: spoilerons, not ailerons

The Sky Pup is two-axis because the design predates the final Part 103 rule and
the industry expected a 220 lb empty weight limit rather than 254. Ailerons were
omitted to hit a number that was never real. It is not a safety decision, but the
result is a spin-proof aircraft, and that is worth keeping.

Spoilerons over ailerons:
- Proverse yaw rather than adverse, because a raised spoiler adds drag on the
  descending wing
- Still effective at high alpha, where an aileron is stalling
- Cannot be cross-controlled into a spin

Cost is asymmetric response and a deadband. Gliders that use them call it adequate
rather than crisp.

**Single-acting, tension-only, spring return to closed.** Airflow and spring both
push them shut, so a broken or disconnected cable retracts rather than floats.
On a two-axis aircraft a stuck-open spoiler is the one control failure with no
good answer, so this is not optional. One cable per side, differential off a stick
bellcrank, roughly 30% of stick travel as deadband.

**Verify the aerodynamic close direction before flight.** Tape a panel on and
measure with a spring scale at 25 and 35 mph. "Usually wants to close" is not a
design basis.

## 10. Slats: mandatory, not optional

At 496 lb on 130 ft²:

| CLmax | Stall | Takeoff | Landing roll |
|---|---|---|---|
| 1.4 clean | 32.7 mph | 180 ft | 108 ft |
| 1.8 slats | 28.8 | 140 | 84 |
| 2.3 slats + slotted flaps | 25.5 | 110 | 65 |

Slats cost CD0 going 0.0373 to 0.0430, so L/D drops 11.5 to 10.7 and glide from
1,000 ft goes 2.18 to 2.03 miles. Seven percent for 40 ft at each end.

**Slats specifically, rather than flaps, because there are no ailerons.**
Spoilerons need attached flow over the outer panel. A slat keeps it flying well
past where a clean wing breaks.

**And slats are what make the Part 103 configuration legal.** At 450 lb loaded,
power-off stall clean is 27.0 kt against the 24 kt limit. With slats, 23.8.
Empty weight was never the only binding criterion.

Slat gap, chord, overlap, and droop should be copied dimension-for-dimension from
a known installation (CH701, Highlander) rather than derived. Millimeters decide
whether a slat works or is pure drag.

**Addendum — superseded (owner decision 2026-08-09): flaps replace the slats.**
This section's "slats, not flaps, because there are no ailerons" argument
assumed flaps would strip the outer panel; the adopted flap is **inboard-only
(~60% span), leaving the spoileron panels on washed-out outer wing** — the tips
keep flying by geometry, verified on the quarter-scale model before the wing
drawings freeze. The swap nets ~−1 lb, moves the 103 stall margin from 0.1 kt
on an unverified slatted CLmax to ~1.2 kt on better-known aerodynamics, and
deletes the slat cruise drag this section priced at 7% of L/D. Worked in
[trades/flaps.md](trades/flaps.md), which carries the escape clause: a wing
drop on the model reverts this decision.

## 11. Brakes: bicycle hydraulic discs

To decelerate 424 lb at 0.4g needs 85 lb of tire friction per wheel, which at a
6.5 in tire radius is 553 in-lb of wheel torque. Through a 203 mm rotor that is
138 lb of pad force. A four-piston downhill caliper makes closer to 800.

**Two pounds against 12–18 for aircraft brakes.** Single-stop heat load is 23 kJ,
which a downhill bike dissipates repeatedly on a long descent.

This is what lets the Part 103 configuration keep brakes instead of deleting them.
Needs a machined rotor-to-hub adapter and a lever lock, since there is no parking
brake.

## 12. Structural design point: 4.7g limit

The most g a wing can generate is (V/Vs)². At Vne 69 and a 32.7 mph stall, that
is 4.65.

**So limit load is set at 4.7g, ultimate at 7.0.** Above that the wing stalls
before it breaks, at any speed in the envelope, with full elevator. The aircraft
cannot be aerodynamically overstressed.

Going from 4.0 to 4.7 limit costs about 4 lb of cap. Going past 7.0 ultimate costs
weight and buys nothing. **Overbuilding past the stall-limited point is not a
safety margin, it is ballast**, and weight is not free: empty 296 to 360 raises
stall speed and therefore impact energy.

Spend margin instead on fittings, bolt bearing, and bonded joints, which is where
manufacturing variability actually lives.

**Correction, from the end-to-end audit
([trades/design-audit.md](trades/design-audit.md)): this section's argument fails
once §10 fixes the slats.** First the arithmetic: (69/32.7)² is 4.45, not 4.65.
Then the substance: with fixed full-span slats, CLmax 1.8 is always available and
the clean 32.7 mph stall never exists in flight. At the slatted stall the g
available at Vne is **5.74 at the design point** (and 6.7 at light weight) — the
wing *can* be aerodynamically overstressed, and pulling to CLmax at Vne needs 23%
more ultimate than is provided. Recommended fix is raising limit load to 5.74 g
(ultimate 8.6) at a cost of roughly 6–10 lb of cap by this section's own pricing,
which honestly restores the stall-protected property for the aircraft as actually
configured. Alternatives — Vne down to ~62 mph, or a tail-authority analysis
showing CLmax is unreachable at speed — are worked in the audit.

Two adjacent gaps from the same audit: **no negative-g case exists** anywhere
(gusts reach −1.9 at Vc, and the §7 spar web wrap is asymmetric top-to-bottom, so
check reversed bending before drawings freeze), and **fixed-mass fittings should
be sized at the light-weight load factor**, since available g rises as weight
falls. Also note full-throttle level flight reaches ~80 mph against a 69 mph Vne —
pick the fixed prop pitch so the engine runs out of rpm near redline.

## 13. Wing joints: bearing, not shear

At an 8 ft center section the joint sits 4 ft out, where moment is about 72,400
in-lb, so 11,490 lb through each cap.

**Bolt bearing in the tube wall governs, not bolt shear.** A 3/8 bolt through both
walls of 1.25 sch 40 gives 0.105 in² of bearing, about 6,300 lb. Less than half
of what is needed.

The internal solid rod plus external sleeve is what fixes it, adding roughly
0.094 in² more bearing. Even then, **two bolts per cap, four per wing**, which
takes margin from 4% to 108%.

The rod's separate job is preventing the tube from ovalizing at the bolt hole,
which is what makes the published bearing allowable actually apply.

Chamfer the rod nose and hold close tolerance only in the last two inches near
each bolt. Loose lead-in, tight where it matters, or a 20 lb panel balanced on
your knee becomes a wrestling match.

## 14. Covering: Stewart waterborne

Over about 430 ft² of total covered area:

| System | Cost | Weight |
|---|---|---|
| Nitrate/butyrate dope | $900 | 37 lb |
| Poly-Fiber (MEK) | $1,150 | 32 lb |
| Stewart waterborne | $1,400 | 24 lb |
| Oratex | $2,800 | 16 lb |

Wood ribs remove the foam-solvent constraint, so dope becomes available. But dope
is the heaviest and slowest option, at ten to twelve coats with sanding between.
With a Part 103 configuration in play, spending 13 lb to save $500 is the wrong
direction.

Oratex buys 75 hours for about $1,400 and is worth considering if hours bind
harder than dollars.

**Addendum (owner decision 2026-08-09): Oratex adopted.** Hours bind harder
than dollars on this build, and Oratex is also the lightest system on the
table — 8 lb under Stewart, on an airframe with a ~1 lb legality margin. The
[second-build](trades/second-build.md) caveat (covering is 27% of aircraft #2
and Oratex pays the premium twice) is acknowledged and accepted: the second
aircraft is deferred until #1 proves out, and covering #1 in Stewart to hedge
a hypothetical #2 would be optimizing the wrong aircraft.

## 15. Engine: Hirth F-33

Designed specifically to fill the niche of the out-of-production Rotax 277, which
is the Sky Pup's own largest specified engine. 28 hp, 35 lb dry including exhaust,
**dual CDI ignition**, free-air cooling via propeller slipstream, 1,000 hour TBO
at 75% power.

Dual ignition is the reason. It removes the most common two-stroke failure, and
the operating site has trees at the end.

Considered and rejected:

- **Half VW**: 85–90 lb for 28–37 hp, and the light version is hand-prop only.
  Four-stroke reliability and direct drive are real advantages, but 45 lb is not.
- **Kawasaki 440**: snowmobile conversion, never condoned by Kawasaki, production
  ended in the early 1980s. Documented CHT hitting 390°F within a minute of
  full-throttle climb against a 395° limit. This aircraft cruises at 55 mph, which
  is the worst cooling environment a free-air two-stroke could ask for.
- **Paramotor engines** (Polini, Vittorazi): light and cheap, but roughly 300 hour
  TBO against 1,000.

## 16. Propeller: 60 in, two blades, wood

60 in rather than 66 because a 66 in disc needs a 45 in thrustline, and a
thrustline that far above the CG gives pitch-down with power, which is a go-around
hazard near the ground. At 40 in the offset is 16 in and the trim change is 30 lb
of tail load rather than 68.

**Two blades, not three or four.** Fewer blades means less total blade wetted area
at a given diameter. Three costs 1–3%, four costs 3–5%. More blades only win when
diameter is constrained.

**Correction: that is true at 1900 rpm and false at 1600.** Worked in
[trades/propeller-blade-count.md](trades/propeller-blade-count.md). Blade count is
not a free-standing choice — it is downstream of diameter and tip speed. Holding
28 hp through a 60 in disc, dropping 1900 → 1600 rpm requires **1.67× the power
coefficient**, and a two-blade prop cannot carry it: blade loading goes from
Cp/σ 0.77 to 1.29, and the chord needed rises from 4.0 to 6.7 in, an aspect ratio
of 4.5. **The two-blade recommendation and the tip-speed recommendation below
cannot both be satisfied.**

Two blades is comfortable to about **1750 rpm** and marginal by 1700, which is
worth **3–4 dB** — roughly half the claimed benefit — with no change to blade
count, hub, or the carved wood plan. That is the recommendation. The full 8 dB
needs three blades, costs about 1.2% cruise efficiency, and quietly deletes the
carved-prop endgame, because three blades means a bolted hub with individually
rooted blades: a part you buy, not a part you carve.

Four and five blades never pay here. At any rpm the engine can turn they are
*under*-loaded — carrying blade area the engine cannot use — at 2–3% in profile
drag, because on a prop this small the narrower blades lose more to Reynolds
number than they regain in tip losses.

Three blades does win on vibration: a two-blade prop produces a 2P pitch and yaw
excitation that three does not, which is a real fatigue input to a belt redrive
and a welded mount.

**And do not shrink the disc to justify more blades.** 48 in buys 6 in of
thrustline and costs 32 ft of takeoff roll — 172 ft against 140 — which spends
most of the margin to the 200 ft target on a trim problem already priced at 30 lb
of tail load. Disc area is the most valuable thing on this aircraft.

**No winglets on the prop.** Tip acceleration is about 3,000g. A tenth-pound
winglet three inches off the blade axis generates 77 ft-lb of bending at the most
heavily loaded point on the blade. Swept or anhedral tips keep the mass in the disc
plane and are worth 3–6% plus a few dB, but they are molded parts, not carved.

**Cut tip speed instead.** Noise goes roughly as the fifth power of tip speed, so
dropping from 1,900 to 1,600 rpm is about 8 dB and costs nothing but a taller
reduction and more pitch. Nothing else on the list comes close.

Two caveats on that, from the blade-count trade. It does **not** cost "nothing but
a taller reduction" — at 1,600 rpm it also costs the two-blade propeller. And the
8 dB assumes sound *pressure* going as tip speed to the fifth; that reproduces as
−7.5 dB, so the number is consistent, but it is very sensitive to the exponent and
a power-based reading gives roughly −3.7 dB instead. Pin it to a measurement
before spending a redrive ratio on it. Check the available belt ratios too — the
F-33 makes power above 6,000 rpm, so 1,600 at the prop is close to 3.9:1, and the
redrive may cap the tip speed reduction before the aerodynamics does.

Advance ratio only ranges 0.39 to 0.48, which is unusually narrow, so fixed pitch
is correct and constant speed is not worth paying for. Buy a cheap ground
adjustable for Phase I, then carve wood once the pitch is known.

## 17. Transport: removable wings, not folding

Folding was designed first, including a hollow fold pin carrying four coaxial
control cable pulleys so that no control ever disconnected. Removable was chosen
instead because a three-piece wing with 20 lb panels is a one-person ten-minute
job, and the fold pin was concentrating too much function in one fitting.

**Cost of that choice: the control disconnects are back**, and they are the
highest-risk item on the aircraft. Mitigated by spoilerons being single-acting
tension-only with spring return, so a disconnected line fails toward closed.

Locking pins are bright red, permanently lanyarded to the underside of the wing,
and pushed up into place, so an unengaged pin hangs visibly below the wing on
walkaround. The lanyard is for seeing, not for retention: use a spring detent or
quarter-turn cam so vibration cannot walk the pin down.

Preflight is a full-deflection check in both directions with eyes on both
spoilerons, not a tug on the stick.

## 18. Tractor, not pusher — and why that answer is different for electric

Full working in [trades/pusher-vs-tractor.md](trades/pusher-vs-tractor.md). The
baseline is unchanged: nose-mounted tractor.

**Efficiency does not decide it.** A tractor gives away 8–11% of cruise power
scrubbing its own slipstream over the fuselage, the open-cockpit pilot, and the
tail — a bigger penalty than the usual 2–5% quoted for light aircraft, because
this airframe is parasite-dominated and the slipstream covers a lot of it. A
pusher recovers that and then spends 4–7% on propeller efficiency lost to
distorted inflow behind the wing and pylon, plus about 4% on pylon parasite drag.
**Net is 0 to +5% for the pusher, inside the error bar on an `f` that was itself
back-solved from a published glide ratio.** Nobody should switch configuration
for a number that small.

**What decides it is the tail.** A tractor's empennage sits in accelerated flow.
On a two-axis aircraft **the rudder is the roll control**, so an unblown tail
loses authority at rotation, in the go-around, and in the low-and-slow regime the
aircraft exists for. That is a handling argument, it never shows up in a drag
calculation, and it is the strongest single reason this design stays a tractor.
Debris off the nosewheel into the disc on a grass strip is the second reason, and
it also conflicts with the carved wood prop of §16.

**Balance is where it gets interesting.** The gas power group — engine, redrive,
mount, 58 lb — has to move aft as a unit, because the engine must be at the
propeller. That shifts empty CG aft 19 in, which forces the wing 12 in aft, which
drives the trailing edge into the volume the disc needs. Move the prop further
back to make room and the CG follows it, the tail arm keeps shrinking, and the
tail has to grow. It diverges. **A gasoline pusher is not a modification of this
fuselage, it is the Quicksilver/Minifox layout with the pilot forward of the
wing** — a new fuselage, cabane, gear, and tail.

**Electric breaks that loop**, and this is the useful finding:

> An electric drivetrain decouples the mass of the powerplant from the location
> of the thrust. Only the motor must be at the propeller. The pack, controller,
> and HV gear go wherever balance wants them.

Of a ~68 lb electric drive group only about 38 lb is forced aft; the pack becomes
a trim tool rather than a trim problem, and it does not move in flight the way
fuel does. With the prop on a pylon about 32 in aft of the wing TE it closes at
the existing seat station, 29–31% MAC across a 130–220 lb pilot range, no ballast.

**So a pusher, if it ever happens, arrives with the electric conversion and not
before.** For the gasoline aircraft the question is closed.

---

## Configurations that lost, with the number

| Considered | Rejected because |
|---|---|
| Canard, Long-EZ style | Cannot use flaps by definition, since the canard must stall first. 14 lb/ft² wing loading, 66 mph stall, 775 ft takeoff. Rutan's own canard sailplane needed mid-span twist to fight canard downwash and still underperformed conventional ships of the same span. |
| Shorter front wing on a tandem | 25% of lift on 53% of the span generates 3.6x the induced drag it would on the main wing. Comes out 14% worse than a plain monoplane. |
| Equal-span tandem wing | Genuinely good: Prandtl's biplane relation gives 22% off induced drag at 15% gap-to-span. But chords fall to 1.4–2.1 ft, Reynolds number drops to 430,000, and you are building 76 ft of wing and folding four panels. Net win about 8%. |
| Pusher propeller, gasoline | Does not close on balance. The 58 lb power group must move aft as a unit, shifting empty CG 19 in aft; rebalancing drives the wing TE into the propeller disc, and chasing it aft shrinks the tail arm and grows the tail. Net cruise efficiency was only 0 to +5% anyway, and the unblown tail costs roll authority on a two-axis aircraft. See [trades/pusher-vs-tractor.md](trades/pusher-vs-tractor.md). |
| Part 103 all-electric | 206 lb of airframe plus a 40 lb electric drive group is 246 lb before any cells, leaving 8 lb of pack against the 254 lb empty cap. 0.6 kWh, four minutes. Batteries count toward empty weight (FAA Chief Counsel, 2012). Not a weight-reduction problem. |
| Ducted fans | Two 16 in fans have one seventh the disc area of a 60 in prop. Propulsive efficiency 0.50 against 0.78, and static thrust 121 lb against 205. Ground roll would go from 180 ft to about 470. |
| Wing-mounted motors | Distributed propulsion exists to let you shrink a wing. At 3.8 lb/ft² there is no wing to shrink. Two 54 in discs over 40% of span buys maybe 8 ft of takeoff roll, and puts a 150A connection across a joint you mate every flight. |
| Series hybrid | Generator, rectifier, inverter, motor is 0.82 end to end against 0.97 for a belt redrive. 18% more fuel for the same thrust, plus a third machine. |
| Aluminum C-channel bonded to birch spar | Aluminum expands 23.6 µm/m/°C, fir 4. Over a 19 ft spar with a 100°F swing the aluminum grows a quarter inch more than the wood it is glued to, absorbed in shear at the bond line, peaking at the ends. |
| Inflated ram-air wing | Dynamic pressure at 37 mph is 0.024 psi. An inflated 6 in beam carries about 2 in-lb; the tail boom alone needs 37,800. The Goodyear Inflatoplane used about 25 psi with a blower running continuously in flight. |
| Heavy duty aluminum foil as sandwich skin | 0.8–1 mil in O temper at 90–120 MPa, against 0.020 in 6061-T6 at 310. Roughly two hundredths of the strength. |
| Solid foam core wing | 39 ft³ of enclosed volume, so 39 lb of foam in 1 lb/ft³ EPS before any skin. Rutan gets away with it on smaller, thinner wings. |
| Amphibious conversion | The prop kills it first: 60-in disc tips at 10 in AGL sit in the bow-spray zone on any float geometry — the Aventura solves this with a pylon pusher, a fiberglass hull, and 328–390 lb empty, i.e. by not being Part 103. The stall gate leaves ~0 lb for floats at 456 lb gross (floats are excluded from *empty* weight, not from stall), and the 103 engine can't climb the hump. Water is a first requirement, not a feature. See [trades/amphibious.md](trades/amphibious.md). |
| Fixed leading-edge slats | Justified on *roll control* for a two-axis wing, then out-analysed by their own case: −7.4% L/D, a millimetre-critical gap, and a stall-limit argument that broke under audit. Replaced by single-lever plain flaps, with vortex generators held in reserve as the escape clause. [trades/flaps.md](trades/flaps.md) |
| 6061-T6 aluminium tail boom | Chosen at rev E, reversed at rev F. A thin-wall boom is buckling-limited rather than strength-limited, so steel's 2.9× stiffness very nearly cancels its 2.89× density — +4.4 lb raw, +2.2 net. Steel also deletes the aluminium-to-steel transition joint and has a true endurance limit where 6061-T6 has none. [trades/cockpit-cage.md](trades/cockpit-cage.md) |
| Cabane struts, wing above the pod | Left 15 in of open air between pod top and wing underside with struts crossing at the widest station. Deleting it and landing the wing on the cabin roof took f from 4.84 to 3.68 ft², L/D 10.8 → 12.4, and gave back 5.5 lb to *both* aircraft. [trades/enclosed-cockpit.md](trades/enclosed-cockpit.md) |
| Full fly-by-wire | No fixed-wing ultralight, LSA or certified light aircraft anywhere has FBW without mechanical reversion. The weight loophole runs backwards — §103.1(e)(1) excludes the chute, not servos. And the twist grip makes hardover worse: a wrist against 61 in-lb at Vne, with no annual and no mandatory inspection of the clutch, ever. [trades/fly-by-wire.md](trades/fly-by-wire.md) |
| Rudder pedals | Deleted with the twist-grip rudder. Emptied the crush-bay footwell of foot traps, saved ~2 lb, retired the adjustable-pedal requirement — and, unforeseen at the time, is the only reason the reclined seat fits without moving CG. [trades/controls-mechanization.md](trades/controls-mechanization.md) |
| Framed seat pan + Confor foam | ~1.8 lb heavier than a mesh sling between the cage rails. The sling alone is a spring, so the energy absorption is kept with a 2 in crushable pad below the 1-g sag point. [trades/seat.md](trades/seat.md) |
| Frangible door attachment for egress | Plasticised PVC elongates 200–400% before breaking, so a shoulder balloons it rather than punching through — and a release window that must hold cabin pressure yet let go under a shoulder drifts the wrong way as UV ages it. Replaced by positive attachment and a mounted pointed film cutter: one diagonal cut, grab, tear, 4–5 s. |
| All-Lexan and all-film glazing | All-Lexan at 0.060 is 8.2 lb; all-film distorts the forward view and, worse, propagates a tear on the one panel that takes stones off the nosewheel. The split — Lexan nose, film doors — costs +1.4 lb and buys an optically clean screen that cannot run. |
| V-tail | NACA equal-projected-area rule: needs the same 45 ft² as the cruciform surfaces it replaces, so no weight saved — the only honest win is two boom junctions instead of four, worthless at a 55 kt cap. Costs a ruddervator mixer, routine saturation when the −19.3° flare meets crosswind rudder on the same two surfaces, and instantaneous adverse roll that fights the rudder-then-dihedral steering this two-axis aircraft turns with. See [trades/v-tail.md](trades/v-tail.md). |

## 19. Fabrication method: digital tooling, not digital parts

Worked in [trades/digital-fabrication.md](trades/digital-fabrication.md). Estimated
**90–160 adjusted hours** across the build, taking 693 to between 537 and 607. The
largest single block is the 85-hour *remakes and learning curve* line, which is
what accuracy upstream actually buys.

**The rule that decides every case: use CNC, laser, and printing for tooling, not
for flight parts.** Tooling has no weight penalty, no fatigue life, and no
airworthiness argument, and a jig that is wrong gets reprinted for two dollars.
§6's tip cap analysis already showed what happens the other way — every printed
option came out 2 to 3× heavier than the laminate it replaced.

Four interventions carry most of it. **One laser-cut 4130 sheet package** for every
flat steel part on the aircraft, which is worth more in symmetry than in hours —
§9 already says roll authority is adequate rather than crisp, and an asymmetric
airframe spends control travel it does not have. **Printed tube coping saddles**,
which apply to the 130-hour fuselage and the 55-hour tail together. **CNC-cut
plywood jigs**, both a fuselage eggcrate and a rib board that makes 31 genuinely
identical ribs, which is what constant chord was chosen for in §6. And **printed
drill jigs with hardened bushings** for the wing joint holes.

Three process notes that belong on the drawings. **Do not laser-cut holes to final
size** — the heat affected zone lands in the bearing surface, and §13 establishes
that bolt bearing governs the entire joint design. Undersize on the laser, ream
after. **Do not laser-cut structural plywood** — char is a weak boundary layer
adhesive cannot bond through, so rout the rib gussets or sand every glue face back
to clean wood. **Print jigs in PLA, not ASA**: it is the most dimensionally stable
common filament, jigs never see sun, and printed fixtures cannot go within a couple
of inches of a tack weld anyway.

**The best use of printing here is not a part, it is a process.** §10 says slat
gap, chord, overlap, and droop decide whether a slat works, at millimetre
resolution, and should be copied rather than derived. Printed bracket sets make
that a measurable parameter — print a set, fly it, change one dimension, print
another. Then the printed brackets end their life as weld fixtures holding the slat
while the real 4130 brackets are tacked. Print to find it, machine to fly it.

**And it does nothing for covering**, which at 120 raw hours is the largest task on
the aircraft. The lever there is material, not method: §14 already prices Oratex at
about 75 hours against Stewart. **That single unresolved decision is worth more
time than every tooling intervention combined.**

**The shop already has five printers, a desktop laser, a desktop CNC, and a Maslow
4 × 8 router**, which removes tooling acquisition from the estimate and makes the
optimistic column the realistic one. Three consequences. The **Maslow enables a
full-size digital loft** — draw once, then cut every template, jig, form and
former at full scale, including the fuselage side-truss layout boards the 130-hour
line currently assumes you improvise. **The desktop laser cannot cut 4130**, so the
sheet package in the trade stays the one outside order. And **five printers make
the coping saddles obviously worth it**, where at one printer the print time merely
competes with coping the tubes by hand.

Two gaps worth closing. There is no lathe for §13's joint rods and sleeves — do not
buy one, **buy precision-ground rod and honed tube stock** instead, since §13 only
needs close tolerance in the last two inches near each bolt. And the carbon tip cap
weight case in §6 depends on vacuum bagging, which needs a $150–300 pump; bagged is
0.54 lb per tip against 1.13 wet-laid, so that pump is the difference between
weight-neutral and a penalty.

**Verify the Maslow's calibration before it cuts the rib jig.** That board defines
the airfoil on all 31 ribs. At a 50 in chord ±1 mm is 0.08% of chord and fine — but
only if it is ±1 mm.

## 20. The common airframe: one structure, both configurations

Worked in [trades/common-airframe.md](trades/common-airframe.md), on top of the
weight scrub. The requirement: the airframe must not change between the Part 103
build and the EAB build — only the powerplant and small additions do.

**It closes.** The invariant airframe is **212 lb** with the full safety package.
The 103 kit (Thor-DS-class engine, 53 in compliance prop) lands at **253.2 lb**;
the EAB kit (F-33 + belt, 60 in prop, windshield, tablet) at **275.7 lb**. Both
balance at 27–34% MAC on the **same wing position** — the engine swap moves CG
about 4% MAC and stays in band, so the wing, cabane, and gear never move.

**The load basis unifies through the absolute-strength framing.** The documented
spar is a 2,331 lb limit / 3,472 lb ultimate structure, and maximum attainable
lift depends only on q. **Placard Vne 62 mph on both kits** and the wing is
stall-protected at every gross with zero added spar weight — resolving the §12
correction (audit Finding 1) by the Vne route for the whole fleet. Load factor
then falls out per weight: 5.1 g available at the 103's 456 lb max, 4.4 g at the
EAB's 526.

**The one real cost: the EAB also lives with Vne 62 and a ~56 mph cruise
placard.** The F-33's surplus becomes climb and short-field margin, not speed.
A 69 mph EAB redline requires the 5.7 g spar on the common structure, which adds
6–10 lb and kills the 103 kit — a common airframe and a fast EAB are mutually
exclusive. If a fast EAB ever matters it is a second spar off the same drawings,
explicitly a different airframe.

Rules that follow, now design requirements: one engine-mount cluster sized for
the heavier engine at light-weight g with per-engine bolt-on adapters; nose and
gear geometry clear the 60 in disc; gear sized at the EAB max gross; all
deletable items (windshield, tablet, BRS bridle) on permanent hard points;
5 gal fuel in both kits; per-kit placards.

**§20 addendum — the fleet plan (see also §21).** Two aircraft, both built to the identical
103-compliant airframe. #1 registers EAB from the start: the stall gate caps the
103 configuration at pilot + fuel ≤ 184 lb, so a 200 lb owner is not legal on it
at any fuel load — EAB is required by the owner's weight before any add-on.
#2 stays pure 103 for the 105 lb pilot, with no N-number, DAR, or inspection.
Design pilot cap 200 lb; fleet max gross 525 for gear and fittings. The BRS tray
gets two permanent positions — sta 40 for the light-pilot aircraft, sta 55 for
the heavy-pilot one, since each fixes a different end of the CG band. Every
airframe carries the hybrid/electric provisions: a 110 lb CG-bay tray at the
carry-through, a nose-to-bay conduit channel, and a 45 lb engine-mount ceiling.
The published design's audience follows the same split: anyone builds the 103;
the EAB kit is the documented growth path on the same structure.

## 21. Owner decisions, 2026-08-09

Five open items closed in one sitting; each points at the trade that priced it.

- **Flaps replace the slats (Path B adopted).** [trades/flaps.md](trades/flaps.md).
  Single-lever plain flap, ~60% span inboard, Johnson bar 0/25/40°, one-piece
  torque tube, VFE 55 mph. 103 stall margin goes 0.1 → ~1.2 kt on
  better-verified aerodynamics; ~−1 lb net (held as margin, not banked, until
  the conversion weight is measured on a scale — the 253.2/275.7 lb ledger
  numbers stand until then). §10's slat arguments superseded per its addendum.
  Escape clause: a wing drop on the quarter-scale model reverts this.
- **Covering: Oratex.** §14 addendum. 75 hours and 8 lb bought for ~$1,400.
- **Second aircraft: deferred until #1 proves out.** The first steel order is
  sized for one aircraft; the DXF nesting is paid regardless, so a second 4130
  set later costs only a repeat shop setup. Revisit after Phase I.
- **Plans are for publication, and the CAD outputs cut files.** The drafting
  standard is set before the first drawing, as
  [trades/digital-fabrication.md](trades/digital-fabrication.md) required:
  3D-first CAD from which DXF and STL fall out, full-size rib templates, a
  materials list with sizes and sources, and an assembly sequence. The
  roughly-triple drafting effort is accepted; this design ships cut files,
  which no other aircraft in its class does.
- **Spoileron servo provision (Junco).** The spoilerons remain the roll/
  crosswind control, manually actuated on this aircraft. Design requirement
  recorded now, while the linkage is undrawn: the spoileron circuit gets a
  **servo attachment provision** so the EAB's Junco tablet can later parallel
  the manual linkage for wing-leveling in crosswind — same pattern as the
  hybrid provisions (grams of bracket now, capability later). The manual
  linkage must always override or back-drive the servo; fail-safe analysis
  joins the EAB autopilot work, not this airframe's critical path.

- **Symmetric spoiler mode: adopted** (owner decision, same date). The
  spoilers get two functions: differential for roll (as designed) and
  **symmetric both-up for glidepath control** — the audit's ~720 → ~480 ft
  improvement on the over-the-trees landing. **Mechanization is deliberately
  open**: the owner may want individual control per side, possibly two
  separate levers. Recorded engineering position for the rigging study:
  differential should stay on the lateral stick motion and symmetric on one
  dedicated lever with a mechanical sum, because the flare needs a hand on
  the stick — two independent spoiler levers puts three controls in two
  hands at the worst moment. Whatever wins, the §9 fail-safe stands:
  spring-return to closed on release, and the symmetric path must never be
  able to hold one side up alone. Decide the lever arrangement before the
  spoileron rigging is drawn; it shares linkage with the Junco servo
  provision above.

Still open after this batch: the spoiler lever arrangement (above), and where
Phase I flight testing happens (needed before the EAB airworthiness
application, not before drawing).

**§21 addendum — controls mechanization decided (owner, same date):** one
stick — elevator fore/aft, spoilerons lateral, **rudder on a twist grip** —
plus the left-hand symmetric spoiler lever; **rudder pedals deleted**. On a
two-axis aircraft this is coherent (rudder-then-dihedral is the turn, and
both roll-producing controls live on independent motions of one wrist), but
it closes physically only with a **~45% horn-balanced rudder and 2.4:1
gearing**: unbalanced, full rudder at 35 mph is ~85 in-lb at the wrist.
Deleting pedals nets ~−2 lb (unbanked), kills the adjustable-pedal
requirement for the 105–200 lb pilot range (seat-only adjustment), and
empties the rev D crush bay's footwell — nothing left to trap feet. Gates:
horn balance sized before the tail freezes; grip/centering-spring behavior
and brake-lever placement verified on the full-size seating mockup. Worked in
[trades/controls-mechanization.md](trades/controls-mechanization.md).

**§21 addendum 2 — seat decided (owner, same date): mesh sling.**
Hammock-style sling mesh between cage rails replaces the framed pan + Confor
foam: cooler, more comfortable, and ~1.8 lb lighter (unbanked). The crash
property is kept, not deleted — a sling alone is a spring, so a 2 in
crushable pad sits ~1.5 in below the 1-g sag point: normal sitting never
touches it, a hard impact crushes it without rebound. Sling carries the
9.6 g × 200 lb case at ~98 lb/in edge tension (~1.5× margin after seam
derate); **static proof test to 1,920 lb required before first flight**.
Harness stays anchored to the cage, never the sling. Worked in
[trades/seat.md](trades/seat.md).

## 22. Borrowed optimizations: what the ultralight world still has to offer

Survey of what this design has *not* mined from the rest of the ultralight
and STOL world, worked in
[trades/borrowed-optimizations.md](trades/borrowed-optimizations.md) with
`analysis/borrowed-optimizations.py`. Six items; none adopted here except
where noted, because five are owner decisions and one is a hole.

- **Vortex generators, as the flaps decision's safety net.** §10 justified
  slats on roll control, not stall speed — *"spoilerons need attached flow
  over the outer panel"* — and §21 deleted the slats. VGs are the STOL
  world's standard active fix for exactly that, weigh ounces, bond to
  Oratex, and are tunable on the flight line. **They cost nothing to hold
  open and they change the escape-clause economics**: a wing drop on the
  quarter-scale model currently reverts the airframe to slats (6 lb, and the
  103 margin with it); with VGs, the first response is a strip of vanes and
  slats become the fallback behind that. Keep the outer-panel leading edge
  accessible and bondable; do not let the tip cap preclude it.
- **The 80% of drag nobody has attacked.** The audit found housekeeping is
  3.94 of 4.84 ft² of flat plate and filed it as housekeeping. Wheel covers
  on the mains (not the castoring nose — side area on a castoring wheel is a
  weathervane), faired legs, and a footwell closeout the deleted pedals just
  made free, total ≈ −0.95 ft²: **cruise L/D +15%, cruise power −13%**, for
  ~1.6 lb. Largest performance number left in the design, and yesterday's
  ~4.8 lb of freed margin is exactly what should buy it.
- **There is no pitch trim system — a hole, not an upgrade.** Elevator stick
  force runs 2.5–2.7 lb across the envelope, and the twist-grip decision put
  pitch and rudder on the same hand, so that force is held by the wrist that
  must also twist for yaw. Fix: bungee/spring trim at the stick base,
  ~0.4 lb, no tab and no new flutter surface. Treat as required equipment.
- **Gap seals — and the sourced answer is subtler than "don't seal the
  rudder."** NACA TN-632 (flight test) gives +20% effectiveness sealing an
  0.18c surface and +33% on 0.09c, and the real lesson is that **a sealed
  smaller surface matched an unsealed larger one at one-third the operating
  force**. So for the twist-grip rudder, sealing is *coupled to sizing* and
  is a live question to ask before the tail is drawn, not a closed one.
  Seal the elevator regardless. **The genuine enemy is friction, not hinge
  moment**: sailplane practice mandates a teflon chafe strip under the seal
  precisely to stop breakout force creeping up — mandatory here, where the
  rudder is worked by a wrist.
- **Ground-adjustable prop — and it need not cost weight.** The EAB-only
  reasoning was wrong on one fact: **GSC makes a ground-adjustable *wood*
  prop** (aluminium hub, maple blades, 36–72 in in 2 in steps, individually
  replaceable blades), which removes the composite-hub weight penalty and
  obsoletes buying two fixed props. Supporting: a nine-prop back-to-back
  test found static thrust 155–196 kg and climb 910–1,034 fpm while **cruise
  fell within 1–2 kt across every prop** — props buy climb, not cruise, which
  is what a 200 ft ground roll wants; pitch is also how a two-stroke's EGT is
  managed, and how Vh is legally set for §103.1(e)(3). **Blocked on one
  number: GSC publishes no hub weight.** If it costs more than ~1 lb over
  fixed wood, the EAB-only split stands after all.
- **The Quicksilver precedent, recorded because it is the cautionary one.**
  The MX — 28 ft span, 250 lb empty, 24 mph stall, near-identical to this
  aircraft — went two-axis with heavy dihedral, added spoilerons that proved
  *"only minimally effective,"* and the next generation moved to true
  ailerons. That is this project's core control decision, tried at this
  scale, and found wanting. The counter-evidence is stronger and the
  distinction is the whole point: Kohlman's flight tests (SAE 770441) of
  aircraft **designed around spoilers** found excellent roll, **yaw coupling
  virtually eliminated**, high roll rates with flaps down, and no deadband or
  lag. Quicksilver's were bolted onto a wing that was not. This design is in
  Kohlman's category — which is the reason to expect the good outcome, and
  the reason the quarter-scale model's roll work is the item that decides
  whether the configuration works at all. Bonus from the same history: the MX
  deployed **both spoilerons symmetrically off the rudder pedals to kill lift
  for short fields** — §21's symmetric mode is recovered practice, not
  invention.
- **Adjustable stabilizer incidence, decided before the tail is welded.**
  The pending gate-3 flap rerun already expects to want ~1° of tail
  incidence; three shim positions at ±0.5° turn a rebuild into a wrench.
- **Field rigging as a numeric requirement**, borrowed from Kolb/Quicksilver
  practice: one person, no helper, 15 minutes, no tools past a pin puller —
  set now so it constrains the joint design instead of being discovered
  after the joints are drawn.

**Bookkeeping catch recorded in the same trade:** the flaps decision handed
back +7.4% of L/D (slat drag deleted) and the audit's Oswald correction took
−6.1%, so the README's 10.7 survives at 10.80 **for entirely different
reasons than the repo states**. Fixing either correction without the other
introduces a real error.

## 23. Fly-by-wire and servo-augmented controls: no, except on one surface

Worked in [trades/fly-by-wire.md](trades/fly-by-wire.md) with
`analysis/fly-by-wire.py`. The question was whether full FBW is worth trying,
or servos supplementing the pilot with manual reversion by cutting power.

**Prior art points the wrong way, and the weight loophole runs backwards.**
Full-FBW ultralights do fly under Part 103 — Pivotal BlackFly (313 lb empty),
Helix (348), Jetson ONE, LIFT HEXA — but they are multirotor/tailsitter eVTOLs
that **cannot be flown by a human without computers**. **No fixed-wing
ultralight, LSA, homebuilt or certified light aircraft anywhere has full FBW
without mechanical reversion** — the closest precedent is NASA's 1972 F-8C,
with an ejection seat. They are legal at 313–348 lb because §103.1(e)(1)
**excludes the ballistic chute and flotation** — ~90+ lb of invisible
hardware. **Servos, computers, wiring and their batteries are not excluded**:
the loophole that makes FBW ultralights legal cannot be used to carry the
FBW.
There is no mechanical system to revert to because none could stabilise
them. FBW appears on ultralights exactly where the airframe is uncontrollable
without it and essentially nowhere else. This aircraft is the opposite case:
its safety is *passive* — Sky Pup stall/spin proofing, no aileron spin mode,
self-righting dihedral, a stall-limited wing. Active protection pays best on
airframes that are passively unsafe.

**Weight closes it.** On the lightest hardware that exists (Garmin GSA 28,
1.4 lb, $975): single-string 3-axis ≈ 9.2 lb, dual-redundant ≈ 17.4, triple —
what the real FBW ultralights use — ≈ 25.6. The 103 kit has 0.8 lb, out by an
order of magnitude. On the EAB single-string fits with +10.1 lb, dual is at
the edge (+1.9), triple is out (−6.3). **The architecture with room to spare
is single-string — precisely the one that must not carry a primary control.**
Power is a second gate: servos draw ~2 A each moving, and many Part 103
engines have a tiny alternator or none, so a control-critical battery needs
full-duration sizing and then a second pack. Every FBW ultralight is an
*electric* aircraft for exactly this reason.

**Hardover, and the twist grip made it worse.** Elevator hardover is
overpowerable — 34 lb of stick at Vne, and a slip clutch limiting authority
to ~11° of 25° keeps override under 15 lb. **The rudder is the problem and it
is self-inflicted**: a pedal rudder lets a pilot push back with a *leg*
(100+ lb); the twist grip caps override at a *wrist* (10–15 in-lb sustained).
A rudder hardover demands 19 in-lb on approach and 61 at Vne. §18 simplified
the cockpit by removing the strongest muscle the pilot had for fighting a
runaway.

**Manual reversion is right; the friction objection became an architecture
rule.** A permanently-coupled slip clutch must sit between normal load and
pilot override — on the twist grip a 9-to-19 in-lb window — so power-off
back-drive leaves ~14 in-lb of dead friction against a 9 in-lb budget. But
the de-clutch escape is **not hypothetical**: the **Garmin GSA 28 uses a
solenoid engagement clutch** that decouples the motor when unpowered, for
"virtually no control system friction with the autopilot turned off", shear
pin deleted. So **engagement-clutch servos mandatory, slip-clutch servos
(Dynon/Trio/TruTrak) disqualified.** The ratio still bites — gear friction is
fixed in in-lb while this aircraft's control forces are unusually small, the
worst ratio of any airframe these products target — and EPS practice warns
that friction compensation runs on the *powered* motor, so a power cut hands
back raw friction plus rotor inertia.

**The Baron, which is the argument that should stick.** A Beech E55 (2019)
suffered pitch-trim runaway with a correctly designed manual override: the
clutch fastener had been overtightened to **45 lb breakaway against a
13 ± 2 lb spec**, and NTSB found the pilot could not physically override it.
The pilot died — and so did a person on the ground inside their own home.
**A slip clutch is not a feature you install, it is one you maintain forever
with a calibrated measurement** — and a Part 103 aircraft has no annual, no
A&P and no mandatory inspection of it, ever. §103.9 (no operation "in a
manner that creates a hazard to other persons or property") is exactly the
rule that fact pattern reaches. Certification arithmetic agrees: Part 23
assumes a 3-second recognition delay (1 on low approach) and operating rules
want twice the altitude loss — at 50 mph that is 220 ft of travel before the
pilot reacts, against 500–800 ft pattern altitude. **A servo with meaningful
authority has no legal operating altitude band in a Part 103 mission.**

**The one exception, and it is already in the plan.** §9 made the spoilerons
single-acting, spring-return-to-closed, because *"a stuck-open spoiler is the
one control failure with no good answer."* That physics does not care whether
the tension came from a cable or a servo — kill power and the surface closes
itself — and a spoileron hardover is the mildest available here, overpowered
by the rudder (and spoilers do not suffer aileron reversal near the stall).
**The §21 spoileron servo provision is not a first step toward FBW; it is the
only surface whose existing fail-safe already covers a servo.** **Caveat from
the sourced pass:** every surveyed autopilot assumes roughly linear aileron
response, and spoilerons are strongly nonlinear with §9's ~30% deadband —
expect PIO or limit-cycle behaviour on the first tuning attempt. Still the
right option; not the easy one.

**There was never a force problem**: elevator 2.6 lb, rudder ~9 in-lb steady,
both solved by the 0.4 lb spring trim and the horn balance already specified.

**What to do instead, in order:** (1) **AoA annunciation, not protection** —
it delivers most of stall protection's benefit with no actuator, no authority
question and nothing that can fail inside the control circuit. Two honest
caveats: **no controlled study quantifies accident-rate reduction from AoA
indicators** (the GAJSC position is a reasoned recommendation, not a measured
outcome), and a complete system is *"not quite two pounds"* — **which the 103
kit cannot afford**, so this is an EAB item (the Junco already supplies the
display and plumbing) and the 103 keeps its stall margin the hard way;
(2) the spoileron servo already planned; (3) electric *trim* if wanted — Ray
Allen T2/T3 actuators weigh **2.5 oz**, *lighter than the 0.4 lb spring*, and
the jackscrew locks rather than flops when power is cut. Trim runaway is
tolerated where surface runaway is not because of four properties that must
all hold — slow, low authority, stops instantly on power cut, residual force
holdable by muscle — and **property four is what failed in the Baron**. The
vendor's "cannot run away" claim is contradicted by builder reports of stuck
switches, chafed wires and welded relays: budget a 1 A breaker, a guarded
switch and a limiting controller; (4) nothing in pitch or yaw. On open-source
autopilots: ArduPilot's own Code of Conduct forbids developers from assisting
manned-aircraft projects — no legal bar for a Part 103 builder, but no bug
triage or peer review either, and there is **no published flight-test report
and no accident report** for a manned ultralight on Pixhawk/ArduPilot, which
is a data void rather than a safety record. The EAB may experiment at altitude as the declared development
platform — it can never make such a system a control the pilot depends on.

## 24. Rev F: the cage, the all-steel airframe, and the frame that does three jobs

Worked in [trades/cockpit-cage.md](trades/cockpit-cage.md) with
`analysis/cage-design.py`; drawn on `drawings/sheets/ST-001.png`.

**The boom returns to steel** (see the §5 addendum): +2.2 lb net, one
material, no transition joint, and 4130's endurance limit against 6061's
absence of one. Rev E's aluminium choice was right on the number it scored
and wrong on the two it did not.

**The cage runs sta 30 to 96 on four longerons**, and its geometry is set by
a convergence rather than by a layout preference. Three independent
requirements land within 2.5 in of each other:

| | Station |
|---|---|
| CG, 30% MAC | 63.0 |
| Front spar, 25% chord | 60.5 |
| Rollover hoop clearing the pilot's head | ~62 |

So they become **one frame at sta 61.5**, which then does three jobs at once:
carries **88% of wing lift** (3,038 lb ultimate, 1,519 per side) straight
into the cage; is the rollover structure over the pilot's head; and sits
**at the CG**, so wing lift feeds essentially no pitching couple into the
fuselage. That last property is the weight saver — a wing pickup offset from
the CG has to react a moment through the longerons, and that is how fuselages
get heavy. The rear frame at sta 80.5 sees only 434 lb and so doubles as the
seat-back and harness-anchor frame for free. Front-spar pickups at z = 64,
±8 in, joined by a cross tube that *is* the carry-through; fittings are
bearing-critical, not bolt-critical.

**The pod is now shaped rather than wrapped** — max section at sta 56 at the
pilot's shoulders, smooth run-out into a visually slimmer 3.5 in boom. One
honest finding recorded: the aft-body closure reaches **21.8° and 26.6°** in
the last two bays against the ~12–15° attached-flow limit, and closing at 12°
would need the taper to start at sta 40, forward of the shoulders. **Some
aft-body separation is inherent to a pod-and-boom with a seated pilot**; it
is already inside the audit's f = 0.45, so it is not a new penalty, but it
fixes the honest moves: start the closure as far forward as the shoulders
allow, keep the run-out unkinked, and do not chase a fully closed teardrop.

**Ledger warning.** All-steel (−2.2) plus the §22 drag cleanup (−1.6) spends
3.8 of the 4.8 lb that flaps, the twist grip and the sling seat freed.
**The margin is now spoken for**; nothing further joins the 103 kit without
finding new weight.

## 25. Rev G: reclined pilot, enclosed cabin, and the wing brought down onto it

Worked in [trades/enclosed-cockpit.md](trades/enclosed-cockpit.md) with
`analysis/enclosed-cockpit.py`. Owner objection: the wing attachment was not
aerodynamic or efficient, the pilot should recline, the windshield should run
from the nose up to the wing, and the cabin should be enclosed with doors.

**The objection was right.** Rev F left **15 in of open air** between the pod
top and the wing underside, with cabane struts crossing it at the widest
station on the aircraft.

**Reclining 35°** drops the head 6.5 in (56 → 49.5). It also swings pilot CG
**5.7 in aft** — +4.3% MAC, at the aft limit — so the **seat moves forward
~6 in** (hip sta 57 → 51) and aircraft CG never moves. The room exists only
because §21 deleted the rudder pedals and emptied the footwell: two decisions
paid for each other without either knowing.

**The wing comes down from chord line 64 to 58** (underside 55, giving 5.5 in
over the head). **The cabane is deleted entirely** — the main hoop at sta 61.5
picks the front spar up directly at the cabin roof, so the load path gets
shorter as well as cleaner.

**Drag: −1.17 ft², f 4.84 → 3.68, L/D max 10.8 → 12.4 (+15%)**; stacked with
the §22 cleanup, **f → 3.08 and L/D 13.6 (+25%)**, glide 2.05 → 2.57 miles
from 1,000 ft. The largest single performance change in the project, and it
came from a shape wanted for looks.

**Weight, and the fleet rule survives:** the cabane deletion is an *airframe*
change worth **−5.5 lb to both aircraft**, taking the **103 kit from 253.2 to
247.7 — margin 0.8 → 6.3 lb**, which more than covers the all-steel boom
(−2.2) and the drag cleanup (−1.6) that had just spoken for everything. The
**enclosure (+7.5 lb net) is an EAB kit item**, exactly like the windshield
and tablet: hard points are permanent grams in the cage, doors bolt on or
stay home. **Aircraft #2 flies open under the same wing on the same cage.**

**Three honest costs recorded.** Roll: the high-wing pendulum arm drops
37 → 31 in above CG, **−16%**, on the aircraft whose roll control *is*
dihedral — expect to put 0.5–1° back, and re-run the aero model before
drawing. Entry: ducking under a 55 in wing is a regression from the 26 in
step-over; doors fix it on the EAB, the open 103 gets a duck-and-sit.
Ventilation: an enclosed cabin in a Tennessee summer is a greenhouse, so
NACA ducts and an openable panel become required equipment — which partly
undercuts the sling seat's cooling rationale (§21 addendum 2). Plus a new
question the open cockpit never had: **egress from an enclosed cabin under a
BRS**, possibly inverted, through doors that share structure with the
rollover hoop.

**§25 addendum — thin-film glazing and ram-air ventilation** (owner
direction; worked in [trades/enclosed-cockpit.md §6](trades/enclosed-cockpit.md)
with `analysis/glazing-ventilation.py`). Glazing is **isinglass-class clear
PVC film, ~20 mil, stretched on the steel frame** rather than Lexan: **3.0 lb
against 8.2**, and the saving compounds because film needs only an edge to
pull against where Lexan needs a frame stiff enough not to crack it. The
enclosure kit drops from 17.0 lb gross to **10.0**, which changes a verdict —
**the Part 103 aircraft can now carry a windshield and vents (no doors) at
250.8 lb, 3.2 lb of margin**, instead of flying open.

**The vents and the film help each other, which was not planned.** A
stretched membrane drums in an airstream unless tensioned; ram air
pressurises the cabin and tensions it from the inside, the inflatable trick.
At 55 mph a 20 in panel bulging 1 in carries **1.34 lb/in** against vinyl's
20+. Design requirement that falls out: **the outlet must be smaller than the
inlet**, or there is no pressurisation and the film flaps.

**Duct sizing is small:** two NACA inlets of ~2 × 2 in (8 in² total) give
**202 CFM at 55 mph**, against the 136 CFM needed to hold the cabin within
10 °F of ambient at ~1,500 BTU/hr. Put them in **rigid structure, not the
film** — a submerged inlet needs a precise 7° ramp it cannot hold in a
membrane.

**Winter, honestly:** film has no R-value, so the cabin gives **still air at
ambient**, not warmth. What it deletes is 55 mph of wind chill — **19 °F at
30 °F ambient, 23 °F at 20 °F**. Two requirements: **a defog trickle that
never fully closes** (a warm pilot inside cold film fogs it instantly), and
**cold-crack-rated vinyl** — ordinary clear PVC embrittles at 20–30 °F where
marine grades go to −20 °F.

**The frangibility claim is corrected.** The intent — push straight through
in an accident — answers the egress question rev G opened, but the mechanism
does not work: plasticised PVC elongates **200–400% before breaking**, so a
shoulder **balloons it like a trampoline** and can be trapped by it. Thin
vinyl is *extensible*, not frangible. **Make the attachment frangible
instead**: bead-in-track or twist fasteners sized to release under a shoulder
push, a zip pullable from inside, and a 2 oz hook knife on the harness. Then
the claim is testable — **proof-test egress on the mockup, both sides, in a
harness.**

**§25 addendum 2 — egress decided: cutters, not a release panel** (owner
decision). A **seatbelt cutter and a film cutter carried in the cab**, with
the film **positively attached** and no release mechanism at all. Better than
the edge-release the trade first proposed, for two reasons: "push through it"
never worked (PVC elongates 200–400% and balloons like a trampoline), and the
release-force window was narrow — a panel must hold ~25 lb of cabin pressure
plus gusts yet let go under a shoulder, and fasteners that satisfy both drift
wrong as UV ages them, while a door departing in flight on a two-axis
aircraft is its own emergency.

**The detail that decides the design: a seatbelt cutter has a shielded hook
blade and cannot puncture.** Against a taut membrane with no edge it does
nothing. So the airframe must supply the start — **a small pre-slit at each
panel's top corner under a tab**, and the cut runs **along the bead track,
not across the middle** (one pass releases the panel; carving a hole in the
middle is slower and needs a point). Carry both tools: hook for webbing and
long runs, a small pointed blade as the backup that can start anywhere.

**Timing:** 86 in of cut releases a door in ~5.7 s at ~15 in/s, plus 2–3 s to
reach and deploy — **7–10 s total.** Fine for ditching or a post-crash exit,
**marginal for fire**, which is the case that sets the standard. Requirements:
**two cutters, one per side; mounted not stowed, findable by feel, retained;
reachable in gloves** (this aircraft flies in winter); and a **timed proof
test** from a fully assembled panel, in a harness, both sides. It does not
cover unconscious or pinned — nothing in this weight class does; the BRS
covers in-flight and the cage covers impact. ~0.3 lb, and it deletes the zip
and the release-force tuning.

**§25 addendum 3 — egress timing corrected, and the hazard it exposes.**
The 7–10 s figure in addendum 2 was wrong: it assumed cutting the whole panel
out. For a thin film **tear propagation is far cheaper than initiation** —
20 mil flexible PVC runs at roughly **10 lbf** of steady pull once a cut
exists — so the real method is **one diagonal cut from a corner, grab the
flap, tear**: about **2 s of work, 4–5 s including reach**. That moves the
fire case from marginal to acceptable, which was the only case in question.
It also settles the tooling: **the pointed film cutter is the primary tool**
(a shielded hook blade cannot puncture a taut membrane and does nothing
without an edge), and the hook cutter earns its place on **webbing**.

**The same property is a flight hazard, and this is the new finding.** A
membrane that tears at 10 lbf once nicked will tear *in flight* once nicked,
and the addendum-1 decision to tension it with cabin pressure primes it. A
stone off the nosewheel, an abrasion at a frame edge, a UV-hardened spot in
year three — any of them can run; at Vne a lifted flap edge peels at well
over 10 lbf. **Mitigation is free, because it is only panel layout: the bead
track is the ripstop.** A tear runs to the edge of its own panel and is
arrested at the frame, so **divide the glazing at every existing cage member**
rather than spanning two big sheets per side, and put the **smallest panels
low and forward** where nicks are likeliest. Explicitly **do not** switch to
scrim-reinforced mesh vinyl: it would stop tears and equally stop the egress
plan — the sling seat uses that material precisely because it must not tear.
Film is a consumable; a nicked panel is replaced, not flown.

**§25 addendum 4 — glazing split: thin Lexan windshield, film doors only.**
Owner refinement, and the right division. **Windshield + upper sides in
0.040 Lexan (3.0 lb), the two doors in 20 mil film (1.4 lb) — 4.3 lb total**,
against 3.0 all-film and 8.2 all-0.060-Lexan. The **+1.4 lb over all-film**
buys two things: the forward view goes through optical-grade rigid panel,
which **deletes the distortion problem a 14–17° raked film screen would have
had**; and the windshield — the one panel actually exposed to stones off the
nosewheel — **cannot propagate a tear at all**, because polycarbonate crazes
locally rather than running like a tensioned membrane.

**That also shrinks addendum 3's tear-arrest requirement.** Film is now only
the doors, which sit high on the sides at sta 40–78, out of the spray, and
are already individually bounded panels. So "subdivide the glazing at every
cage member" **relaxes to: keep each door a single bounded panel**, which it
already is. Scrim-reinforced mesh is still explicitly out — it would defeat
egress.

**Three Lexan-specific requirements that film did not have:** **thermal
float** — polycarbonate expands ~6× steel, so a 40 in screen moves 0.15 in
through a 120 °F swing and needs oversized holes or a floating channel,
**never a hard clamp**; **oil-canning** — 0.040 is thin for a 12 ft² wrapped
panel and may want an intermediate frame member or 0.060 (+1.5 lb), a mockup
check before the frame is welded; and **solvent crazing** — keep it off the
fuel path and specify the cleaning method.

**Fleet consequence:** the split costs the 103 about 1.9 lb, taking its
windshield-and-vents configuration from 3.2 lb of margin to 1.3. Clean
answer: **glazing is a kit item either way.** The EAB takes the Lexan screen,
being the aircraft flown fast, far and in weather; **Avery's 103 can keep a
film screen and hold 3.2 lb** — same cage, same frame, same bead track,
different sheet. The doors stay film in both, so **the egress plan is
identical: the doors are the escape path in either build.**

### Addendum 5 — the glazing becomes geometry, and a shaded render of it

Everything above was carried as prose and a weight line. It is now in the
mesh: `analysis/geometry-mesh.py` **cuts the glazing out of the fabric pod**
and carries it as its own surfaces, so the split is geometry rather than a
note. The pod skin is lofted on a fine grid and masked by station and by
`phi`, the angle around the section from the top centreline:

| Surface | Station | phi from top | Material |
|---|---|---|---|
| `glass` — windshield + upper sides | 14 → 48 (wing LE) | ≤ 45° | 0.040 Lexan |
| `film` — the two doors | 40 → 78 | 48° → 116° | 20 mil PVC |
| `fuse` — fabric | everything else to sta 96 | — | Oratex |
| `boom` — the tail boom | 96 → 184 | — | painted 4130 |

The 3° strip between the two masks is the door header, left as fabric.

**One thing the mesh was missing turned up while cutting the hole**: there was
**no member along the glazing boundary** for the windshield to attach to. The
cage ran longerons and hoops but nothing followed the `phi` = 45° line. Added
as `wsframe` — light tube from sta 14 to 48 both sides plus a bow across the
front. That is the **"windshield frame / floating channel"** line already
carried in the enclosure ledger at 1.0 lb, so **no weight change** — the
ledger was ahead of the geometry, not the other way round.

**`analysis/render-hero.py`** shades that mesh: Lambert + Blinn-Phong,
sky-dome ambient, **Fresnel-weighted transparency** so the glazing goes white
at grazing angles and clear head-on (which is what makes the cage and the
seated pilot visible through it), smoothed vertex normals, projected soft
shadow, and a filmic highlight roll-off. Rib scalloping at the true 11 in
pitch and the paint scheme are **shading only — there are no ribs and no paint
in the mesh.** The pilot figure is built in the render script, not in
`geometry-mesh.py`: he is a prop and does not belong in the STL or on the
drawings.

Outputs `drawings/renders/hero-{ramp,cockpit,air}.png`. **They are renderings
of the design geometry. They are not photographs, and this aircraft has not
been built** — every image carries that on its face.

## 26. Rev H: the whole front is windshield, and the first number for visibility

**Owner direction: "the sight lines and visibility are terrible in these
renderings. The entire front should be a windshield. The engine cowling is the
only thing that's not transparent."**

That is a correct reading of rev G, and the repo deserved a worse verdict than
it got: **there was no visibility number anywhere in it.** Twenty-five sections
of trades, and the enclosure was justified on drag, weight, wind chill and
egress — never on what the pilot can see. Fixed here, and the analysis is what
decides the shape. Script: `analysis/visibility.py`.

### What changed in the geometry

`phi` is the angle around the fuselage section from the top centreline.

| Surface | Station | phi | rev G | rev H |
|---|---|---|---|---|
| cowl | 2 → 22 | all | fabric, and *glazed* above 14 | **opaque, its own group** |
| windshield | 22 → 48 | ≤ **136°** | glazed only to 45° | **glazed to the lower longeron** |
| side lights | 48 → 78 | 20°–46° | fabric | **glazed** |
| doors | 40 → 78 | 48°–116° | film | film, unchanged |

The 136° lower edge is not arbitrary: **the cage's own lower longeron already
sits at phi ≈ 135°**, so the glazing runs down to a member that exists. Nothing
was added to carry its bottom edge.

### Ray-cast from the pilot's eye

Möller–Trumbore against the real mesh, from the eye at sta 58 / z 45.5, over
the whole sphere. Every triangle is tagged by its group, so a ray comes back
glazed, blocked, or clear. Same mesh and same eye for both revisions — only
the masks differ.

| Sector | rev G sees out | rev H | change |
|---|---|---|---|
| whole sphere | 40.0% | **61.3%** | **+21.3%** |
| forward hemisphere | 45.3% | 67.9% | +22.6% |
| abeam, both sides | 51.1% | 73.9% | +22.9% |
| the approach window | 48.9% | 74.7% | +25.8% |
| **ahead and down, ±30°** | **4.2%** | **41.9%** | **+37.7%** |

That last row is the one that matters. **Rev G could see 4% of the sector a
pilot actually uses to land.**

How far down the view reaches, by azimuth (fan test — a 3/8 in tube is not a
wall, so it takes half a ±6° fan going dark to count as blocked):

| Azimuth | rev G | rev H |
|---|---|---|
| straight ahead | −8° | **blocked at the horizon** |
| 10° off the nose | −3° | −5° |
| 20° off | blocked | **−21°** |
| 30° off | −13° | **−47°** |
| 45° and outboard | −41° | −41° |

### Two findings, and one of them is not good news

**1. Straight ahead, rev H is worse on paper — and that is a correction, not a
regression.** Rev G's windshield started at sta 14, so it drew glass across
sta 14–22. **That is where the engine is.** Rev G was crediting the pilot with
a view straight through the powerplant. The cowl now runs 2 → 22 and takes the
fiction away. The straight-ahead view was never there; the model stopped
claiming it.

**2. The cowl is the limit, and glass cannot fix it.** The cowl crown is at
z 47.3 and the eye at 45.5 — **the crown sits 1.8 in above the eye, so the
pilot must look 2.9° UP to clear the nose.** The thrustline is at z = 40
because the propeller has to clear the ground; the engine sits around the
thrustline; the cowl has to cover the engine. There is an **engine** in the
way, not a fairing.

**And the cowl may not even be tall enough.** A crown at 47.3 gives the engine
7.3 in above the crank centreline. **A Hirth F-33's cylinder standing upright
is taller than that.** So either the engine gets clocked or tilted to fit under
this line, or the cowl grows — and if it grows the forward view gets *worse*.
**This is now the open item that decides the forward view, and it is a
powerplant question, not a glazing one.** Nothing is settled until an engine is
on the bench and measured.

What rev H genuinely buys is everything *either side* of the cowl: the aiming
point, the runway edge and the flare picture arrive over the **side** of the
nose, through continuous glazing from the centreline round to the door. Same
technique a Cub pilot uses, without the S-turn, because nothing is opaque
between the two.

### The wraparound is not developable — this is what it costs

Flat sheet cold-forms into **single** curvature only, and the pod's forward
sections are doubly curved. So the screen cannot be one piece: it is a **centre
panel and two side panels per side**, meeting on frame rails at phi 45° and
95°, with bows at the cowl joint (22) and the wing leading edge (48). Same
reason a Champ or a Cub has a split screen.

**Measured off the mesh**, not assumed:

| Line | rev G | rev H |
|---|---|---|
| glass, 0.040 Lexan | 12.0 ft², 3.0 lb | 12.8 ft², **3.2 lb** |
| film doors, 20 mil | 10.0 ft², 1.4 lb | 11.1 ft², **1.5 lb** |
| glazing frame | 1.0 lb (assumed) | **2.6 lb** (303 in of 3/8 × .028 measured) |
| **enclosure kit gross** | **12.4 lb** | **14.4 lb** |

**The frame, not the glass, is the whole delta.** Open item: it has had no
materials pass — aluminium extrusion, a smaller tube, or deleting the phi = 95
rail if 0.060 sheet proves stiff enough are all live.

### What it costs the Part 103 aircraft

| 103, windshield + vents, no doors | Weight | Margin |
|---|---|---|
| rev G, film screen | 250.8 | +3.2 |
| rev G, 0.040 Lexan | 252.7 | +1.3 |
| rev H, film screen | 253.1 | **+0.9** |
| rev H, 0.040 Lexan | 254.5 | **−0.5** |

**The 103 can no longer afford the Lexan nose.** The fleet answer §25 reached
for optical reasons is now load-bearing: **glazing is a kit item.** The EAB
gets Lexan; **Avery's 103 gets film in the same frame and the same bead track**
and holds +0.9 lb. If the 103 wants Lexan, 1.5 lb has to come off that airframe
first.

`drawings/visibility.png` plots the field of view. `drawings/renders/hero-eye.png`
renders it — from the eye, on short final, with the cowl the only thing in the
way.

## 27. The frame becomes data, and the data fails its first check

**Owner direction: CAD files, to start reconfiguring the steel tube layout.**

The useful deliverable here is not a file. It is that the frame stops being
thirty hard-coded `strut()` calls buried in the mesh generator and becomes
**`analysis/frame.py`: a node table, a member table and a stock table** — which
every other script now reads. Move a node and the STL, the drawings, the cut
list, the weight, the renders and the visibility numbers all follow. That is
what makes a layout reconfigurable; a DXF on its own does not.

### What ships

`analysis/cad-export.py` writes, into `cad/`:

| File | What it is |
|---|---|
| `nuthatch-frame-3d.dxf` | 3D wireframe of every tube centreline, layered by structure group, with node markers, labels and datum/station reference lines. R12 ASCII on purpose — everything reads it |
| `nuthatch-views-2d.dxf` | side / top / front on one flat sheet with a station grid and waterlines |
| `nuthatch-frame.scr` | an AutoCAD script that draws the same wireframe with `LINE` commands, for when a DXF import argues |
| `tube-schedule.csv` | cut list: stock, centreline length, weight, and **the tightest joint angle at each end**, because that is what sets the fishmouth |
| `nodes.csv` | every node, mirrored, with the members landing on it |

Inches, aircraft datum, ground at z = 0. And it reads back: `cad-export.py
--from-dxf FILE` parses `LINE` entities out of an edited DXF, diffs them
against `frame.py`, and prints a node table to paste in. Positions only — a DXF
line cannot tell you what stock it is meant to be.

**Recommended CAD: Onshape on the free plan**, whose *Frames* tool sweeps tube
profiles down a wireframe and generates a cut list with miter angles. Its free
tier requires public documents, which for a CERN-OHL-S project is where the CAD
belongs anyway. FreeCAD if it has to be offline and open source; SolidWorks
Weldments is still the best tool for this specific job if it is available.
AutoCAD does what was asked — the DXF is native `LINE` geometry on sensible
layers — it just will not give a cut list back, which is what the round trip is
for. `cad/README.md` carries the workflow.

### And then the check failed

Because the frame is now a graph, a question can be asked that the tube mesh
could not answer: **do these tubes actually meet?** Overlapping cylinders look
welded. `frame.check()` tests degree, connected components, and nodes that sit
*near* a member without being on it.

**The frame is in six disconnected pieces.** Only the 14-node cage box is one
structure. The **rear frame** — rear spar carry-through, seat back and harness
anchor — is an island whose feet sit **2.70 in** off the lower longeron. The
**tail boom** floats 3.00 in between the aft-frame crosses. All three **gear
legs** are islands. The **nose bow is a U, not a hoop** — there is a crown and
no lower cross member — so the nose leg has nothing to attach to at all. And
inside the cage box, **the main hoop feet miss the longerons by 3.44 in** — on
the frame that carries 88% of wing lift and is the rollover structure.

None of this is new damage. It has been in the geometry since rev F and it was
invisible because the only view of it was a picture. **A drawing cannot tell
you whether two tubes meet; a graph can.** That is the whole argument for the
refactor, and it paid for itself on the first run.

**Nothing was moved.** The coordinates are exactly what rev G carried — fixing
this is a design decision about which joints want to be welded and which want
to be bolted fittings, and it is the owner's to make. `frame.py` will re-check
whatever comes back. Listed member by member in `docs/open-questions.md`.

**Also recorded honestly:** the tube schedule totals **48.4 lb** (27.5 cage,
13.2 boom, 7.7 gear) with no gussets, no fittings and no weld metal, against
40 lb in a build-log CSV that predates the pod-and-boom architecture. Those do
not reconcile, and *workbook reconciliation* was already on the list.

**And the visibility numbers moved, by a little.** §26 was computed before the
frame carried real tube stock; the cage members now have their schedule
diameters and the boom is constant-section, so the ray-cast sees slightly more
steel. Whole sphere 61.8 → **61.3%**, ahead-and-down 42.3 → **41.9%**. The
tables in §26 have been restated. Nothing about the argument changes, but the
number in the repo should be the number the script prints.

**One correction fell out of the refactor:** the mesh had been drawing the tail
boom as a **taper**, 7 in deep at the pod junction down to 3.5 at the tail,
while the design of record is a **constant-section 3.50 × .049 tube**. The loft
now takes its radius from `frame.TUBE["boom"]`, so the picture and the schedule
cannot disagree again.

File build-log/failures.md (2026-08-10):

# Failures

Everyone publishes the airplane that flew. Almost nobody publishes the three
motor mounts that cracked first, and that is the part that saves the next person
a year.

Log everything that did not work: parts remade, bond lines that failed a peel
test, dimensions that were wrong, tools that were the wrong choice, and hours
spent on approaches that got abandoned.

Format: date, what was attempted, what happened, what was done instead.

**Log actual hours per task alongside this.** Every estimate in `analysis/` and in
`docs/trades/` sits on the Hours sheet, which carries a 0.7 factor described as
"your estimate of my estimates." Measured hours replace the guess — and they are
what turns [docs/trades/second-build.md](../docs/trades/second-build.md) from
judgement into arithmetic.

---

*(empty, build has not started)*

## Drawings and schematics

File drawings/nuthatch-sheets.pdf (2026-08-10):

## TOP VIEW

## ISOMETRIC

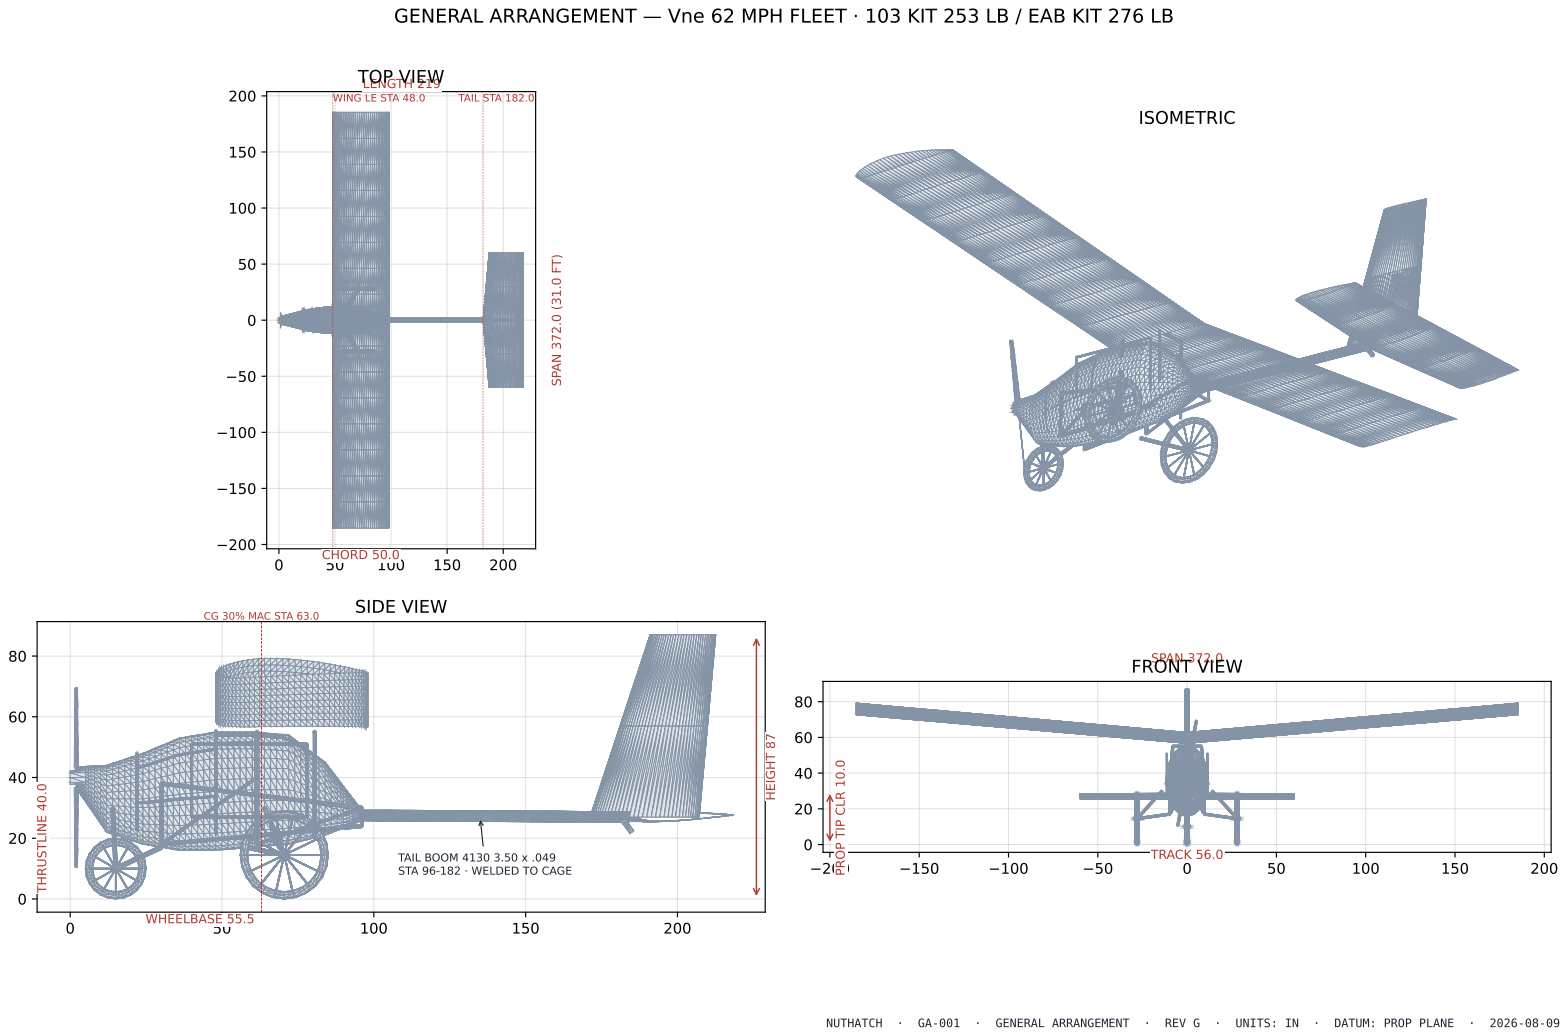
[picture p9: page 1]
CHORD 50.0; SPAN 372.0 (31.0 FT); LENGTH 219; WING LE STA 48.0; TAIL STA; HEIGHT 87; THRUSTLINE 40.0; WHEELBASE 55.5; SIDE VIEW; TRACK 56.0; NUTHATCH; GENERAL ARRANGEMENT; REV G; UNITS: IN; DATUM: PROP PLANE

GENERAL ARRANGEMENT — Vne 62 MPH FLEET · 103 KIT 253 LB / EAB KIT 276 LB

CG 30% MAC STA 63.0

SPAN 372.0 FRONT VIEW

PROP TIP CLR 10.0

TAIL BOOM 4130 3.50 x .049
STA 96-182 · WELDED TO CAGE

## LANDING GEAR — GRASS / EASY ENTRY / DAMPED (trades/landing-gear.md)

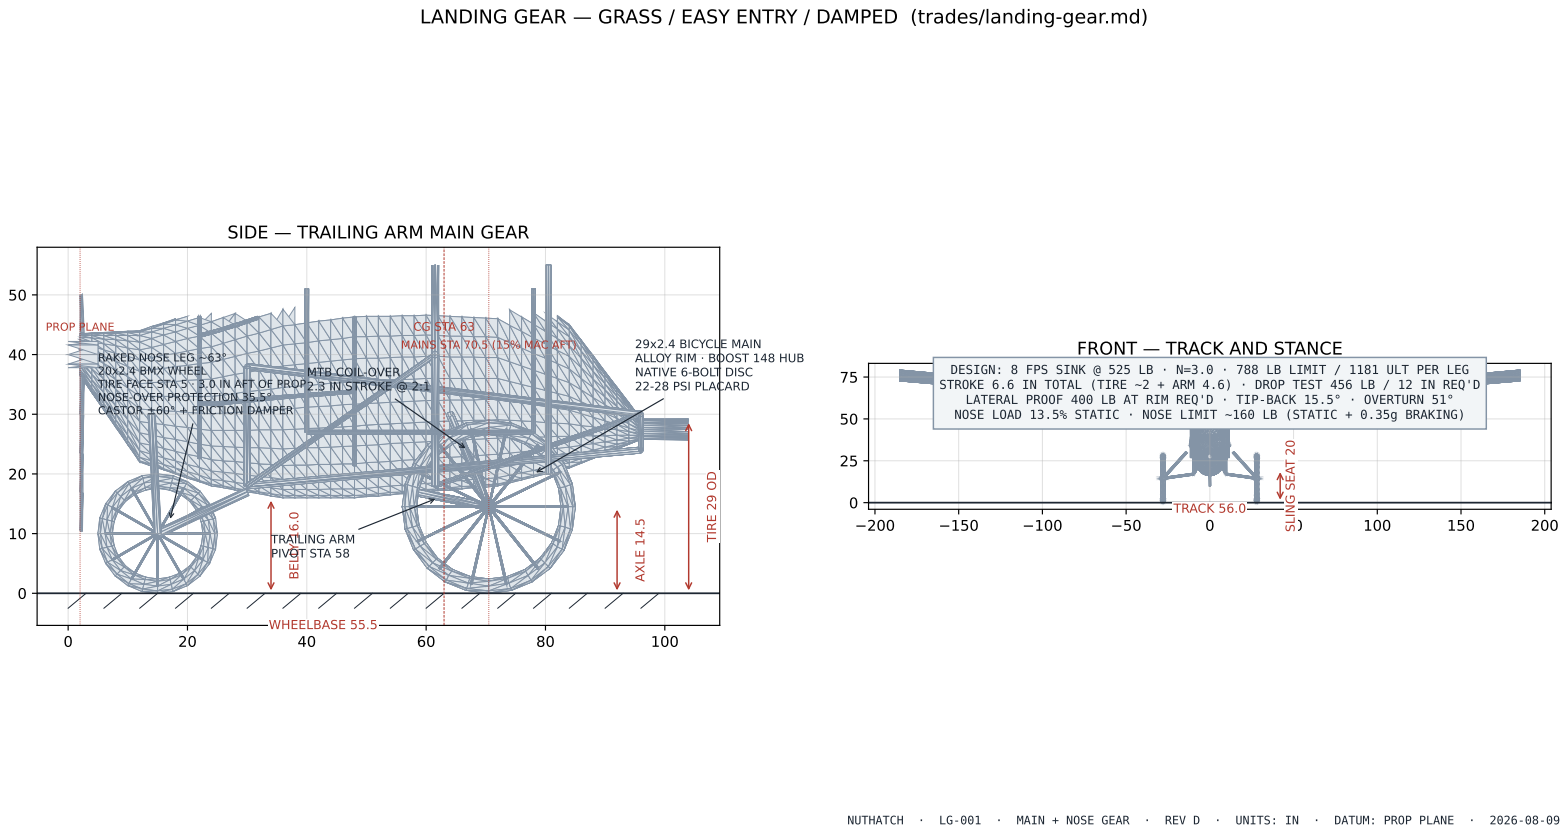
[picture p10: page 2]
WHEELBASE 55.5 BELLY 16.0; AXLE 14.5; TIRE 29 OD; 20x2.4 BMX WHEEL; CASTOR ±60° +; FRICTION; DAMPER; TRAILING ARM; PIVOT; STA 58; TRACK 56.0; SLING SEAT 20; NUTHATCH; MAIN + NOSE GEAR; REV D; UNITS: IN; DATUM: PROP PLANE

SIDE — TRAILING ARM MAIN GEAR

PROP | PLANE | | CG MAINS | STA 63 STA 70.5 | (15% MAC | AFT)

FRONT — TRACK AND STANCE

29x2.4 BICYCLE MAIN
ALLOY RIM · BOOST 148 HUB
NATIVE 6-BOLT DISC
22-28 PSI PLACARD

RAKED NOSE LEG ~63° TIRE FACE STA 5 NOSE-OVER PROTECTION 35.5° | · 3.0 IN AFT OF PROP | | MTB COIL-OVER 2.3 IN STROKE @ 2:1

DESIGN: 8 FPS SINK @ 525 LB · N=3.0 · 788 LB LIMIT / 1181 ULT PER LEG
STROKE 6.6 IN TOTAL (TIRE ~2 + ARM 4.6) · DROP TEST 456 LB / 12 IN REQ'D
LATERAL PROOF 400 LB AT RIM REQ'D · TIP-BACK 15.5° · OVERTURN 51°
NOSE LOAD 13.5% STATIC · NOSE LIMIT ~160 LB (STATIC + 0.35g BRAKING)

## COCKPIT & ENTRY — SIDE

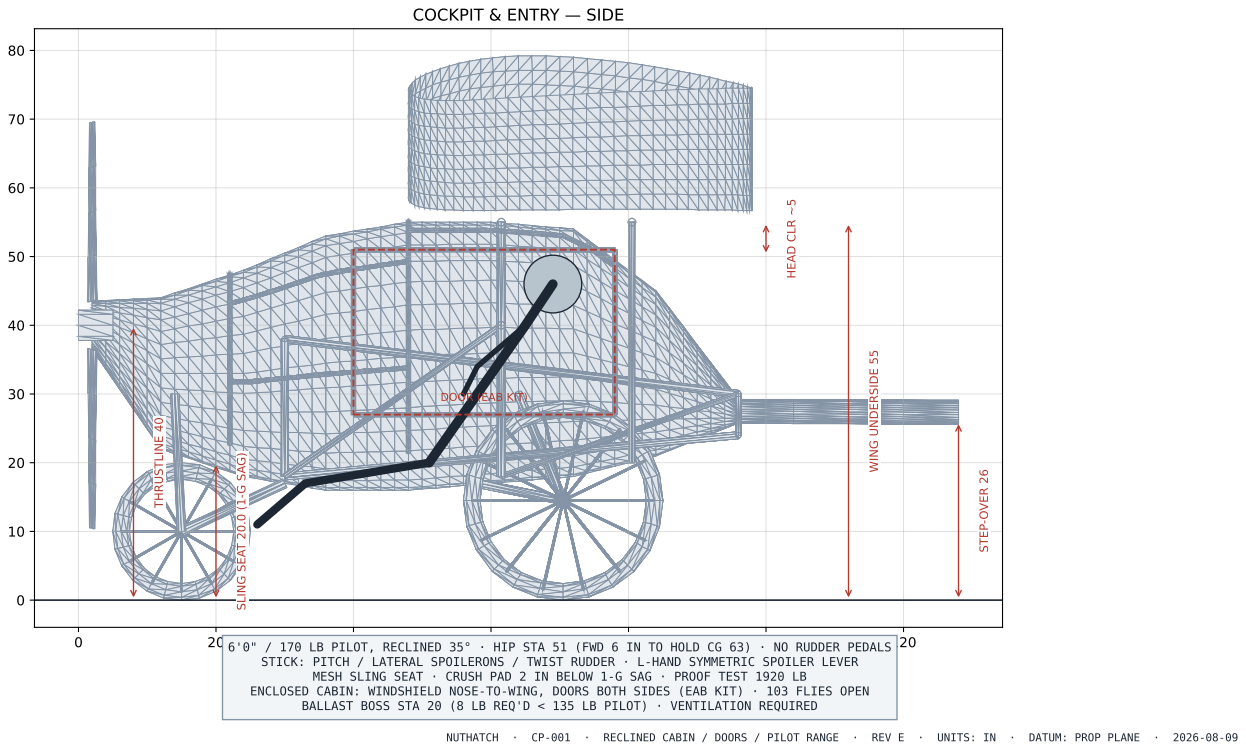
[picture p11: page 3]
STEP-OVER 26; THRUSTLINE 40; HEAD CLR ~5; WING UNDERSIDE 55; NUTHATCH; RECLINED CABIN / DOORS / PILOT RANGE; REV E; UNITS: IN; DATUM: PROP PLANE

DOOR (EAB KIT)

SLING SEAT 20.0 (1-G SAG)

6'0" / 170 LB PILOT, RECLINED 35° · HIP STA 51 (FWD 6 IN TO HOLD CG 63) · NO RUDDER PEDALS
STICK: PITCH / LATERAL SPOILERONS / TWIST RUDDER · L-HAND SYMMETRIC SPOILER LEVER

MESH SLING SEAT · CRUSH PAD 2 IN BELOW 1-G SAG · PROOF TEST 1920 LB

ENCLOSED CABIN: WINDSHIELD NOSE-TO-WING, DOORS BOTH SIDES (EAB KIT) · 103 FLIES OPEN

BALLAST BOSS STA 20 (8 LB REQ'D < 135 LB PILOT) · VENTILATION REQUIRED

## STRUCTURE — WELDED 4130 CAGE + STEEL BOOM (trades/cockpit-cage.md)

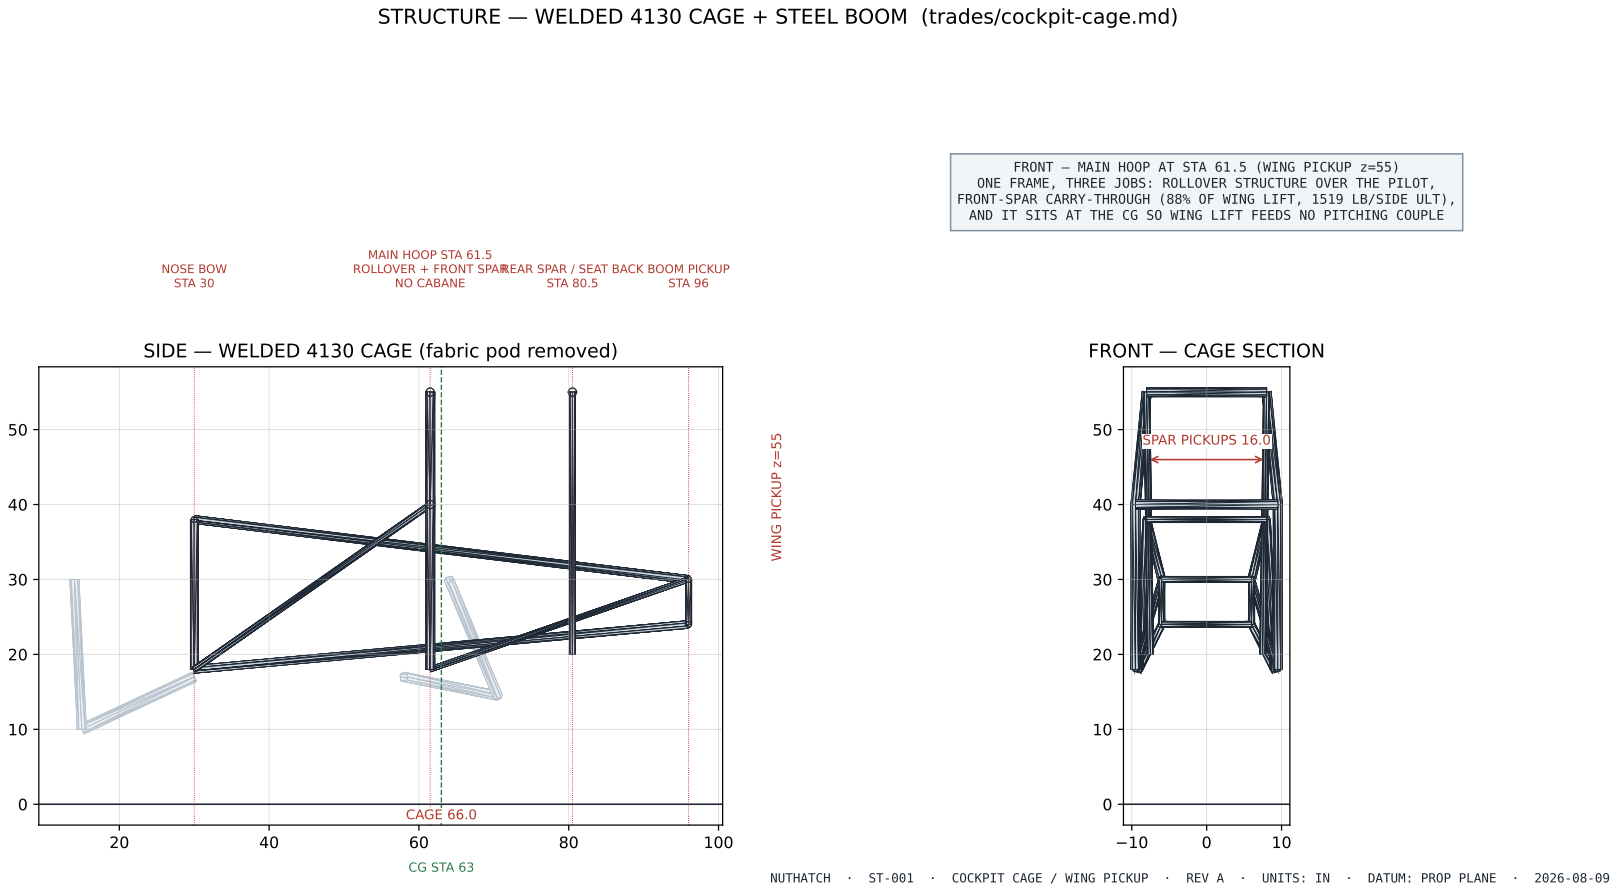
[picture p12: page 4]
NOSE BOW STA 30; NO CABANE; STA 80.5; BOOM PICKUP STA 96; CG STA 63; CAGE; WING PICKUP z=55; SPAR PICKUPS 16.0; NUTHATCH; COCKPIT CAGE / WING PICKUP; REV A; UNITS: IN; DATUM: PROP PLANE

FRONT — MAIN HOOP AT STA 61.5 (WING PICKUP z=55)
ONE FRAME, THREE JOBS: ROLLOVER STRUCTURE OVER THE PILOT,
FRONT-SPAR CARRY-THROUGH (88% OF WING LIFT, 1519 LB/SIDE ULT),
AND IT SITS AT THE CG SO WING LIFT FEEDS NO PITCHING COUPLE

MAIN HOOP STA 61.5
ROLLOVER + FRONT SPAR

REAR SPAR / SEAT BACK

SIDE — WELDED 4130 CAGE (fabric pod removed)

FRONT — CAGE SECTION

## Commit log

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2026-08-08 Add pusher vs tractor trade study; settle electric configuration questions
    Analysis only. No change to the aircraft: the baseline remains a nose-mounted
    tractor with the Hirth F-33.
    docs/trades/pusher-vs-tractor.md answers three questions that were being asked
    informally:
    1. Is a pusher more efficient? No, it is a wash. A tractor gives away 8-11% of
    cruise power scrubbing its slipstream over the fuselage, the open-cockpit
    pilot, and the tail - more than the usual 2-5% because this airframe is
    parasite-dominated. A pusher recovers that and spends 4-7% on prop efficiency
    lost to distorted inflow plus ~4% on pylon parasite. Net 0 to +5%, inside the
    error bar on an f that was ba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
2026-08-08 Add propeller blade count trade; §16's blade count and tip speed conflict
    Analysis only. No change to the design.
    docs/trades/propeller-blade-count.md works the 3/4/5-blade question and finds
    that §16 contains a contradiction: two blades is correct at 60 in and 1900 rpm,
    but §16 also recommends dropping to 1600 rpm for ~8 dB, and at 1600 rpm a
    two-blade prop has run out of solidity.
    Holding 28 hp through a 60 in disc, 1900 -> 1600 rpm needs 1.67x the power
    coefficient. Blade loading goes Cp/sigma 0.77 -> 1.29 and the chord needed rises
    4.0 -> 6.7 in, an aspect ratio of 4.5. Three blades puts it back at 0.86.
    The useful result is where two blades actually runs out: comfortable to ~1750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
2026-08-08 Add winglet trade; shape the tips instead, and flag the missing flutter analysis
    docs/trades/winglets.md works the carbon wingtip winglet question. Winglets do
    return +3 to +4.5% L/D at buildable sizes, which is real, but they are the wrong
    lever here for three reasons that stack.
    Span is not constrained. The wing is already 3-piece removable, so the 22 ft
    garage and 16 ft trailer bound the panel, not the span. One foot of span beats a
    1.0 ft winglet and adds 4 sq ft of wing on the way past. Winglets exist to buy
    span efficiency when you cannot buy span.
    The tip shape has not been spent yet and it is free. Every number in this project
    rests on e = 0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
2026-08-08 Add carbon wingtip cap note: build it, but print the mould female
    Resolves the winglet trade constructively. Moulded carbon tip caps are
    recommended - unlike winglets, this one is worth building.
    Weight: 2 ply 3.7 oz cloth vacuum bagged is 0.54 lb per tip against 0.65 lb for a
    laminated wood bow with fabric. Weight neutral, so the tip-mass and flutter
    objection that killed the winglet does not apply. Resin fraction is the entire
    budget - bagged runs 55% fibre, wet hand layup 40%, and heavy twill wet is +1.9 lb
    over both tips for no benefit.
    The real argument is not surface finish. A Hoerner tip's defining feature is a
    sharp lower outboard corner, and fabric over a wood bow cannot hold a sh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
2026-08-08 Evaluate printed ASA tips: good Phase I development part, wrong final part
    ASA is 2.0 GPa against ~45 for a quasi-iso carbon laminate. Panel stiffness goes
    as E*t^3, so matching a 0.5 mm carbon skin needs 1.4 mm of ASA. At Vne a 6 x 10 in
    unsupported bay carries 5 lb, so 0.8 mm oil-cans; with printed-in ribs every 3 in
    the wall can stay at 1.2-1.6 mm.
    That lands at 3-4 lb across both tips against 1.07 lb for bagged carbon and 1.30
    for a wood bow - 60-75% of the winglet mass penalty the winglet trade just
    rejected, arriving on a part that was supposed to be weight-neutral. Milder than a
    winglet because the mass wraps onto the tip instead of cantilevering outboard and
    adds no lifting surface,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
2026-08-08 Evaluate fibre-filled ASA for tip caps: lateral move, prefer glass over carbon
    CF-ASA raises modulus 2.0 -> 5.5 GPa, which on paper allows a 1.01 mm wall against
    1.41 for neat ASA. It does not cash out.
    Chopped fibre bridges and clogs a 0.4 mm nozzle, so CF filament wants 0.5-0.6 mm.
    Two perimeters at 0.6 is 1.2 mm, so the thin wall is unreachable - and at the same
    1.2 mm geometry the denser filament is heavier, 3.13 lb against 3.01. The
    stiffness cashes out in rib spacing instead: bay width for equal stiffness scales
    as (E*t^3)^(1/4), so about 28% wider bays at the same wall.
    The property it costs is the one that matters here. Elongation drops from 10-20%
    to 1-3% and impact resistance goe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
2026-08-08 Revise digital fabrication trade for the shop that actually exists
    Five 3D printers, a desktop laser cutter, a desktop CNC, and a Maslow 4x8 router.
    That removes tooling acquisition from the estimate and makes the optimistic column
    the realistic one - most of the gap between conservative and optimistic was tooling
    access and print throughput, and neither is a constraint.
    Three conclusions change.
    The Maslow enables a full-size digital loft rather than just faster jigs. A 4x8
    work area is larger than every part on the aircraft except the spar, so the whole
    mylar-lofting workflow gets replaced: fuselage side-truss layout boards (two
    spliced sheets for the 190 in fuselage), the eggcrate stati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
2026-08-08 End-to-end design audit: load basis fails with fixed slats, plus four findings
    Full simulation pass re-deriving every published number from the workbook's own
    model, then stressing the design log's claims against it. All performance numbers
    reproduce (stall speeds, 140 ft roll, ~1050 fpm, 10.7 glide, range, CG band, tail
    volumes Vh 0.56 / Vv 0.038). The load basis does not.
    Finding 1, structural: section 12's stall-limit argument uses the clean 32.7 mph
    stall, but section 10 makes the slats fixed and full-span, so CLmax 1.8 is always
    available and the clean stall never exists in flight. At the slatted stall, g
    available at Vne is 5.74 at design weight (6.7 at light weight) against a 4.7
    lim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
2026-08-08 Add parametric aero model, 3D mesh, STL, and general-arrangement drawing
    analysis/aero-model.py: AeroSandbox model built from the weight-sheet stations -
    NeuralFoil section polars at the real Reynolds numbers, VLM stability check, and
    component-buildup drag. analysis/geometry-mesh.py generates model/nuthatch.stl
    (binary, inches, also usable scaled for the quarter-scale RC build) and
    drawings/general-arrangement.png, the repo's first actual drawing.
    Results, recorded as an addendum to the design audit:
    The CLmax 1.4 assumption is sound. NACA 4412 makes 1.61 in 2-D at stall Re
    (about 1.45 on the wing). 4412 is the working candidate: best cruise drag of the
    candidates, 12% thick for spar dept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
    [nuthatch.stl]
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2026-08-08 Weight scrub for a 103-first single build: workbook missing 12 lb, engine decides
    analysis/weight-scrub.py and docs/trades/weight-scrub-103.md.
    Finding 1, and it comes before any scrubbing: the repo's two weight statements
    disagree by 13.5 lb. The workbook Weight sheet - source of the README's 296 lb
    empty and the "103 strip 250, 4 lb under" claim - has no line for the slats
    (6 lb) or the cabane (6 lb) that measured-weights.csv carries. Honest totals:
    EAB ~308, 103 strip ~262 - 8 lb OVER the 254 limit, not 4 under. Reconcile the
    workbook before quoting it. README table now carries a correction footnote.
    Finding 2: the two Part 103 gates converge. At CLmax 1.8 on 130 sq ft the 24 kt
    power-o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
2026-08-08 Define the common airframe: 212 lb invariant, two kits, one Vne
    docs/trades/common-airframe.md and analysis/common-airframe.py, plus design-log
    section 20. Requirement: the airframe must be identical between the Part 103
    build and the EAB build - only powerplant and small additions change.
    It closes. The invariant airframe is 212.2 lb with the full safety package. Two
    delta kits: Part 103 (Thor-DS-class ~31 lb engine, 53 in compliance prop) lands
    at 253.2 lb empty; EAB (F-33 + belt, 60 in prop, windshield, Junco tablet) at
    275.7 lb. Both configurations balance inside 25-35% MAC on the same wing
    position - the engine swap shifts CG about 4% MAC and stays in band, so the
    wing, cabane, and gea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
2026-08-08 Light-pilot case: 105 lb pilot busts aft CG; forward BRS canister fixes it
    Fleet decision recorded: fast EAB abandoned, Vne 62 fleet-wide is final. The
    EAB is the heavy-pilot/add-on aircraft; the 103 kit must fly a 105 lb pilot.
    The 105 lb case is lighter than anything analysed before and it finds a real
    problem: CG walks aft as fuel burns, from 33.8% MAC at full fuel to 36.3% at
    empty tank - aft of the 35% limit.
    The fix is the parachute. Mounting the BRS canister forward at ~station 40
    (19 lb, excluded from the 254 count under 103.1(e)(1) but real for balance)
    pulls the entire fuel range back into band: 31.4-33.6% MAC, with stall
    21.8-22.7 kt. One installation solves the light-pilot bala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
2026-08-08 Fleet plan: two 103-built airframes, 200 lb pilot cap, per-aircraft chute slot
    common-airframe.md section 8 and design-log section 20 addendum.
    Decided: two aircraft, both built to the identical 103-compliant airframe spec.
    Aircraft 1 registers EAB from the start and is the experiment platform
    (autopilot + Junco ~4-7 lb, larger engine, hybrid propulsion). Aircraft 2 stays
    pure Part 103 for the 105 lb pilot - no N-number, DAR, or inspection, which is
    where the save-time-on-compliance goal lands, along with every future copy by
    other builders.
    Stated honestly: aircraft 1 is EAB because of the owner's weight before any
    add-on. The stall gate caps the 103 configuration at pilot + fuel <= 184 l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
2026-08-08 Owner is 170 lb; ballast chosen over forward chute for the light pilot
    Two corrections to common-airframe sections 7-8.
    The owner weighs 170 lb, not the 200 lb design assumption, and that changes the
    legality picture for the better: without a chute the 103 kit's max-weight
    budget is 202.8 lb, so 170 + full 5 gal = 200.0 lb is legal with 2.8 lb margin
    (CG 31.8-33.8%, stall 23.9 kt at max). Both pilots can legally fly either
    103-configured aircraft. Aircraft #1 registers EAB by choice - for the add-ons
    and hybrid experiments - not by necessity. The 200 lb cap remains as the
    structural design case only.
    The light-pilot CG fix is now nose ballast (decided), not the forward chute:
    8 lb at stati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
2026-08-08 Landing gear design: low grass stance, 8 fps energy basis, geometry resolved
    analysis/gear-design.py and docs/trades/landing-gear.md, resolving the gear
    geometry open question. Requirements: grass field, easy entry for a 6'0"/170 lb
    pilot, strong and forgiving. All three pull the same direction - down.
    Stance: belly 16 in AGL, seat pan ~20 in (kitchen-chair height - sit down, not
    climb in), step-over ~26 in with the cabane strut as grab handle, wing underside
    64 in clearing a seated 6-footer by ~8 in. Thrustline stays 40 in; 60 in prop
    keeps 10 in static tip clearance and +2.5 in at full stroke plus flat tire.
    Energy: 8 fps design sink at the 525 lb fleet max (student-proof margin over the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
    [nuthatch.stl]
2026-08-08 Gear revision: adopt MTB coil-over shocks, reject 8-in mains, per-field tires
    The scooter-tire proposal splits into two halves with opposite verdicts,
    recorded in landing-gear.md section 7.
    The shock half is adopted and is better than the sprung-leg spec. Spring 4130
    legs store landing energy and return it - that return is the bounce - and the
    only damping in the original architecture was the soft tire. Trailing-arm mains
    with mountain-bike downhill coil-over shocks add real, adjustable rebound
    damping: 2:1 lever gives 2.3 in shock stroke for 4.6 in wheel travel at 1,576
    lb shock force at limit. DH coil shocks are ~1 lb, $60-150, with swappable
    springs, so each aircraft in the fleet gets a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
2026-08-08 Adopt large-narrow bicycle main wheels; delete the rotor adapter
    landing-gear.md section 7a. The refined proposal - 20x2.4 BMX/DH-class or
    24x2.6 bicycle wheels - is the opposite corner of the tire trade from the
    rejected 8-in scooter wheel, and the shock adoption changed the physics in its
    favour.
    Bump crossing over a 2 in clump (drag/load): 8-in scooter 1.73, 13x5.00-6
    1.04, 20x2.4 bike 0.75, 24x2.6 0.66. Diameter is what grass taxes and the bike
    wheel has the most. Narrow works now because the MTB coil-overs took over the
    damping job: a stiff dual-ply DH casing at 22-28 psi on 4.6 in of damped
    trailing-arm travel is a better energy chain than a fat tire on an undamped
    spring leg.
    Weight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
2026-08-08 Gear wheels: use the owned high-performance MTB wheelsets, prefer aluminum rims
    landing-gear.md 7a refinement. The wheels in hand are high-end aluminum/carbon
    MTB wheelsets with sub-2 lb tires: pair lands at the light end (~6-7 lb with
    sealant) at zero cost, and a 29er crosses the 2 in bump at 0.59.
    Materials call: prefer the aluminum rims for the gear. Aluminum fails by
    denting and keeps rolling; carbon fails by cracking suddenly and a hard-landing
    crack is tap-test-hard to see. For a forgiving gear the dent is the right
    failure mode. Carbon acceptable with a post-hard-landing inspection protocol
    and a tire insert; the spar undetectable-void objection does not carry to a
    factory-molded rim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
2026-08-09 Flaps trade: feasible, and best as a flaps-for-slats swap (open decision)
    docs/trades/flaps.md + analysis/flaps.py. Plain hinged flaps fit this wing
    unusually well: no ailerons means ~60% span of free trailing edge, a
    one-piece torque tube makes asymmetric deployment impossible, and VFE 55 mph
    preserves the spar-protection load basis with a 7 mph gap under Vne 62.
    Path A (add to slatted wing, CLmax ~2.35, stall 20.9 kt) busts the 254 lb
    cap by ~4 lb and cannot be a kit item, so it dies for the fleet. Path B
    (flaps replace slats, CLmax ~1.95) nets ~-1 lb, moves the 103 stall-gate
    margin from 0.1 kt to ~1.2 kt on better-verified aerodynamics, and deletes
    slat cruise drag - at the price of the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
2026-08-09 Amphibious trade: rejected; the Aventura comparison corrected
    docs/trades/amphibious.md. The Aventura family are pylon-PUSHER flying
    boats (the pusher exists to keep the prop out of bow spray), and the
    Aventura UL at 328-390 lb empty is not Part 103 - it is evidence the 103
    amphibian doesn't close, not that it does. For the Nuthatch: the 60-in
    tractor disc with tips at 10 in AGL sits in the spray zone on any float
    geometry; the 24-kt stall gate leaves ~0 lb for floats at 456 lb gross
    (Part 103 excludes floats from empty weight but not from the stall
    equation); and the 103 engine cannot climb the displacement hump. Flaps
    Path B would relax the stall-gate arithmetic (~494 lb) but the propeller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
2026-08-09 Amphibious follow-up: inflatable floats accounting; the prop still loses
    The gear-for-floats swap genuinely improves the Part 103 empty weight:
    remove 29.5 lb of wheel gear, add ~18 lb of attach structure, exclude the
    Full-Lotus-class inflatable floats per 103.1 -> 241.7 lb with 12.3 lb of
    margin. But gross rises to ~496 lb, so the 24-kt stall gate fails on slats
    (24.9 kt) and only squeaks by with flaps Path B (23.9 kt). The unfixable
    half: floats sized for this gross put their bows ~16 in forward of the
    prop plane - the disc overhangs the bows - and raising the fuselage on a
    ~30 in tower adds weight, wrecks water roll stability and entry height,
    and still leaves the disc over the bow spray.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
2026-08-09 Pusher follow-up: pylon mount and remote belt drive both fail the invariants
    New 4a in pusher-vs-tractor.md. Quicksilver/Aventura pylons balance because
    their pilot sits forward of the wing as the counterweight; the Nuthatch's
    pilot-at-CG invariant (what lets 105-200 lb pilots share one airplane with
    an 8 lb ballast placard) removes that option - a pusher engine at ~sta 99
    needs ~38 lb of permanent nose ballast, or the wing chases aft into the
    documented divergence. A remote belt drive (engine in the CG bay, belt to a
    prop shaft) solves the mass but needs a 45-60 in center distance vs the
    6-10 in of proven redrives, carries two-stroke torsional resonance (the
    BD-5 lesson) across flexing wood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
2026-08-09 High-tractor follow-up: raising the engine solves balance and spray, loses pitch
    New 4b in pusher-vs-tractor.md. A nose-mast high tractor (PBY/Goose/AirCam
    precedent) keeps the engine station - balance preserved, no ballast - and
    puts prop tips ~40 in above the waterline. The wall it hits: thrust 48 in
    above the CG makes 8,640 in-lb of power-pitch moment at takeoff thrust,
    which at 30 mph rotation demands tail dCL 1.05 (~30 deg elevator) - more
    authority than the tail possesses; even a 60-in thrustline consumes 21 of
    the 25 deg throw. Big flying boats absorb this with bigger tails, higher q,
    and three axes; a two-axis aircraft with 5.7 deg of flare margin cannot.
    Gas's 58 lb now fails low-fo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
2026-08-09 High-tractor addendum: no minimum raise exists that clears the bow spray
    Extends 4b in pusher-vs-tractor.md. The disc sits over the float BOW ROOT
    (bows ~16 in forward of the prop plane), the wettest station on the rig -
    the Cub's 30-in rule applies five feet aft of the bows over clean water.
    Over the bows, light chop wants tips 36-48 in up (thrustline 66-78), the
    already-shown exceeds-the-tail case. Modest raises (46-50 in) stay inside
    the bow fan while eating the pitch budget. The closing corner is the
    skip/bounce recovery - full power plus flare elevator, routine seaplane
    technique: flare -19.3 deg + power demand saturates the 25 deg throw at a
    46 in thrustline (28 deg total) and worsens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
2026-08-09 Fuselage architecture rev E: welded cockpit cage + single straight tail boom
    The full-length welded truss was never a decided requirement — the steel
    argument only covered the concentrated-load hardware forward of sta 96.
    Adopt Kolb-style architecture: 4130 cage to sta 96, one 6061-T6 5.00 x .065
    drawn-tube boom to the tail post (+26% ultimate margin at Vne tail loads,
    ~80 fishmouth joints and the aft jig deleted, cables inside the boom).
    Cockpit fairing is non-structural: stringers and fabric, shape free.
    - analysis/fuselage-boom.py: tail loads, boom candidates w/ local-buckling
    knockdown, stiffness/frequency for the flutter item, aft-truss comparison
    - docs/trades/fuselage-architectur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
    [nuthatch.stl]
2026-08-09 Owner decisions 2026-08-09: flaps Path B, Oratex, publication-grade plans w/ cut files
    - Flaps replace the slats (design-log SS10 addendum + SS21): inboard ~60% span
    keeps the spoileron panels on washed-out outer wing; quarter-scale stall
    demo is the escape clause; ledger re-baselines after the conversion is
    weighed. README spec table and configuration list updated.
    - Covering: Oratex (SS14 addendum) - hours and 8 lb over Stewart, second-build
    caveat accepted because the second aircraft is deferred until #1 proves out.
    - Plans are for publication and the CAD outputs cut files (drafting standard
    fixed before the first drawing, per the digital-fabrication trade).
    - Spoileron servo pr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
2026-08-09 Symmetric spoiler mode adopted; lever mechanization left open
    Both-up glidepath mode joins differential roll as a required spoiler
    function (~720 -> ~480 ft over the 50 ft trees). Lever arrangement is the
    owner's open question - individual per-side control vs one summed symmetric
    lever; recorded recommendation keeps differential on the lateral stick since
    the flare needs a hand there. Fail-safes recorded as non-negotiable:
    spring-return closed, no single-side hang-up from the symmetric path,
    Junco-servo compatibility.
    Claude-Session: https://claude.ai/code/session_014aiDFjHLBGVtrchQ4G326m
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2026-08-09 Seat: mesh sling adopted, with the crash property kept
    Owner decision: hammock-style sling mesh between cage rails replaces the
    framed pan + Confor foam. Cooler, conforms better, ~1.8 lb lighter
    (unbanked). The energy-absorbing claim survives via a 2 in crushable pad
    ~1.5 in below the 1-g sag point: normal sitting never touches it, a hard
    vertical impact strokes into it without rebound; the gear stays the primary
    absorber. Sling carries 9.6g x 200 lb at ~98 lb/in edge tension (~1.5x after
    seam derate); static proof test to 1,920 lb required before first flight.
    Harness anchors stay on the cage, never the sling. Fit for the 105-200 lb
    range becomes lacing-tuned sag + adjustable footrest.
    ana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
2026-08-09 Borrowed optimizations survey: what the ultralight world still has to offer
    Six items this design has not mined, plus one bookkeeping catch.
    The two that matter most:
    - Vortex generators. SS10 justified slats on ROLL CONTROL ('spoilerons need
    attached flow over the outer panel'), and SS21 deleted the slats; the only
    mitigation on record is passive (washout + inboard flaps + a model test)
    with a 6 lb revert-to-slats escape clause. VGs are the STOL world's active
    fix for exactly that property, weigh ounces, bond to Oratex, tune on the
    flight line, and cost nothing to hold open - which makes them the
    first-line remedy ahead of reverting the flaps decision.
    - The 80% of drag the aud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
2026-08-09 Rev F: welded 4130 cage, all-steel boom, shaped fabric pod, wing onto the cage
    Reverses rev E's aluminium boom after re-running it fairly, and designs the
    cage the wing actually attaches to.
    BOOM BACK TO STEEL. Over the tube sizes actually stocked, 4130 3.50 x .049
    costs +4.4 lb raw against the 6061 5.00 x .065, and +2.2 lb NET once welded
    boom-root and tail-post clusters replace a machined sleeve joint and bolted
    brackets. The gap is small because a thin-wall boom is BUCKLING-limited, not
    strength-limited: steel's 2.9x stiffness nearly cancels its 2.89x density and
    it never gets to use its 95 ksi. Two things rev E did not score then decide
    it - the aluminium-to-steel transition joint disap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
    [nuthatch.stl]
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2026-08-10 Glazing becomes geometry; shaded renderings of rev G
    The Lexan windshield and the film doors were prose and a weight line. They
    are now cut out of the fabric pod in geometry-mesh.py and carried as their
    own surfaces (glass, film), with the tail boom split out as its own group.
    Cutting the hole exposed a missing member: nothing in the cage followed the
    glazing boundary, so the windshield had nothing to attach to. Added wsframe -
    the 1.0 lb windshield frame / floating channel already in the enclosure
    ledger, so no weight change.
    Adds analysis/render-hero.py: Lambert + Blinn-Phong, sky-dome ambient,
    Fresnel-weighted transparency on the glazing, smoothed vertex normals,
    projected soft shadow a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
    [nuthatch.stl]
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2026-08-10 The frame becomes data: node/member table, CAD export, and a failed check
    Owner asked for CAD files to start reconfiguring the steel tube layout. The
    files are the smaller half of that. analysis/frame.py replaces thirty hardcoded
    strut() calls inside the mesh generator with a node table, a member table and a
    stock table; geometry-mesh.py now reads it, so moving a node updates the STL,
    the drawings, the cut list, the weight and the visibility numbers together.
    analysis/cad-export.py writes cad/: a 3D DXF wireframe layered by structure
    group with node labels and datum lines, a 2D three-view sheet with a station
    grid, an AutoCAD .scr, a tube schedule carrying centreline lengths and the
    tightes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
    [nodes.csv, nuthatch-frame-3d.dxf, nuthatch-views-2d.dxf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]
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
